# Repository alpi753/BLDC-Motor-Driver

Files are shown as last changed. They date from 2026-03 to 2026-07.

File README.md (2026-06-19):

# BLDC Motor Driver

Open-source BLDC ESC firmware for STM32 targets plus a desktop telemetry console. The repo contains KiCad hardware designs, two firmware builds (STM32F411 and STM32G431), and an Electron dashboard that decodes live motor data over USB.

Part of the broader [BLDC-Motor-Driver](https://github.com/alpi753/BLDC-Motor-Driver) project.

## Repository layout

```
PCB/
├── hardware/              KiCad schematics and PCBs (ESC, MCU, MOSFET boards)
├── software/
│   ├── console/           Electron + React telemetry dashboard
│   ├── stm32f411/         STM32F411CE firmware (CubeMX + CMake)
│   ├── stm32g431/         STM32G431CB firmware (CubeMX + CMake)
│   ├── shared/bsp/        Shared motor control, telemetry, USB/CBOR, DroneCAN
│   └── scripts/           Host-side utilities (e.g. telem_reader.py)
└── AGENTS.md              Contributor and AI-agent guide (architecture, protocol, gaps)
```

## Quick start

### Console (dashboard)

```bash
cd software/console
npm install
npm run dev
```

Linux USB serial access usually requires membership in the `dialout` group:

```bash
sudo usermod -a -G dialout $USER   # re-login required
```

### Firmware

Prerequisites: `arm-none-eabi-gcc`, `cmake`, `ninja` (and `openocd` for flashing).

**STM32F411**

```bash
cd software/stm32f411
cmake --preset Debug
cmake --build --preset Debug
make flash    # optional — ST-Link + OpenOCD
```

**STM32G431**

```bash
cd software/stm32g431
cmake --preset Debug
cmake --build --preset Debug
make flash
```

Select the board at configure time with `-DBLDC_BOARD=stm32f411` or `-DBLDC_BOARD=stm32g431` (default is `stm32g431` in the shared BSP CMake).

DroneCAN DSDL codegen (first build only, if `dsdl_generated/` is missing):

```bash
cd software/stm32f411   # or stm32g431
make dsdl_gen_build
```

## How it fits together

```
┌─────────────────────┐     USB CDC 115200 baud      ┌──────────────────────┐
│  STM32F411 / G431   │  CBOR [type, payload]        │  Electron main       │
│  TelemThread (~1Hz) │ ───────────────────────────► │  serial.ts decoder   │
│                     │ ◄─────────────────────────── │  ipc → React cards   │
└─────────────────────┘   settings CBOR (RX only)   └──────────────────────┘
         │
         ├── TIM1 complementary PWM → DRV8323 → 3-phase bridge
         ├── SPI1 → DRV8323R (enable, faults, gain, OC)
         └── ADC → phase currents, bus voltage, NTC temperature
```

Connect the board over USB, open the console, pick the CDC serial port, and dashboard cards update from live telemetry.

## Telemetry today

Both boards publish the same CBOR telemetry map when `CONFIG_BLDC_TELEM_USE_DEMO=n` (current default on both).

| Data | F411 | G431 |
|---|---|---|
| Phase currents (`i_a`–`i_c`) | Real — ADC1 DMA, PA0–PA2 | Real — ADC1 injected, PA0–PA2 |
| Bus voltage (`v_bat`) | Real — PA5 (`ADC1_IN5`) | Real — PB2 (`ADC2_IN12`) |
| Phase voltages (`v_a`–`v_c`) | Real — PWM duty × Vbus | Real — PWM duty × Vbus |
| FET temperature (`temp`) | Real — PA6 NTC, IIR filtered | Real — PA6 NTC, IIR + CORDIC/FMAC |
| Energy used (`e_used`) | Real — integrated V×I | Real — integrated V×I |
| Battery current (`i_bat`) | Approx — mean \|phase currents\| | Same |
| RPM, FOC (`i_d`/`i_q`), angles, observer fields | Stubbed 0 | Stubbed 0 |
| Energy remaining (`e_rem`) | Always 0 | Always 0 |
| Motor NTC (PA7) | Sampled, not telemetered | Sampled, not telemetered |

Telemetry rate is about **1 Hz** (one CBOR frame per second from `TelemThread`).

## What's not done yet

- Sensorless FOC and speed/position observers (RPM, angles, `i_d`/`i_q` stay at zero)
- Console settings UI → firmware settings over CBOR
- DroneCAN on the wire (libcanard layer exists; CAN HAL TX/RX not hooked up)
- `energy_rem` from battery capacity

For UI development without hardware, set `CONFIG_BLDC_TELEM_USE_DEMO=y` in the target's `software/shared/bsp/boards/<board>/board.conf` and rebuild.

## Documentation

- **[AGENTS.md](AGENTS.md)** — Full architecture, protocol reference, board differences, coding rules, and common tasks for contributors and AI agents.
- **[software/console/README.md](software/console/README.md)** — Console-specific setup, IPC API, and UI structure.

## License

No root-level LICENSE file is present yet. Check individual components and submodules for their terms.

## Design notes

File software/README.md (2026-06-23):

# BLDC Motor Driver

Open-source BLDC ESC firmware for STM32 targets plus a desktop telemetry console. This  two contains firmware builds (for both STM32F411 and STM32G431), and an Electron dashboard that decodes live motor data over USB (CAN in the future).

## Quick start

### Console

Linux USB serial access usually requires membership in the `dialout` group:

```bash
sudo usermod -a -G dialout $USER   # re-login required
```
Then: 

```bash
cd software/console
npm install
npm run dev
```

### Firmware

```bash
cd software/<board>
cmake --preset Debug -DBLDC_BOARD=<board>
cmake --build --preset Debug
make flash    # optional — ST-Link + OpenOCD
```

## How it fits together

```
┌─────────────────────┐  Trapezoid Comm./┌─────────────────────┐                              ┌──────────────────────┐
│  BLDC Motor         │  FOC Commutation │  STM32F411 / G431   │  CBOR [type, payload](TX/RX) │  Electron nodejs     │
│                     │◄─────────────────│  Telem     (~1Hz)   │ ───────────────────────────► │  decoder             │
│                     │◄─────────────────│                     │ ◄─────────────────────────── │      ipc → UI        │
└─────────────────────┘◄─────────────────└─────────────────────┘                              └──────────────────────┘
                              P.W.M          │
                                             ├── TIM1 complementary PWM → DRV8323 → 3-phase bridge
                                             ├── SPI1 → DRV8323R (enable, faults, gain, OC)
                                             └── ADC → phase currents, bus voltage, NTC temperature
```
           
Connect the board over USB, open the console, pick the CDC serial port, and dashboard cards update from live telemetry.

Telemetry rate is about **1 Hz** (one CBOR frame per second from `TelemThread`).

## What's not done yet

- Sensorless FOC and speed/position observers (RPM, angles, `i_d`/`i_q` stay at zero)
- DroneCAN not fully implemented yet.

For UI development without hardware, set `CONFIG_BLDC_TELEM_USE_DEMO=y` in the target's `software/shared/bsp/boards/<board>/board.conf` and rebuild.

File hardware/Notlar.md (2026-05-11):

## Motor sürücü devresi hakkında genel notlar

  Mosfet sürücü entegresinin akım sınırı yeterli mi analiz et.

Vin kaynağı için voltaj regülatörü ayarlanacak. İstediğim 6-60V aralığı, şimdilik elimde olan lm294 6-26V regülatörü kullanacağım.

Gate drievr entegresinin besleme hattına paralel kolda bağlı olan seri kapasitör bypass işi görmektedir. Yüksek frekans darbeleri emer ve devredeki ani akım çekimlerinde voltajı sabit tutma işi görür.

--high side - low side sürme
--faz Akım, faz gerilim, zıt emk rpm, mosfet sıcaklığı, rejeneratif kazanç??, kart sıcaklık bilgilerini toplama;  trickle charge pump to support 100% duty cycle. Bunun için;
Mosfet sürücü seçme / Devre kurma

%100 duty cycle destekli bootstrap devresi nasıl kurulur.

DRV8302- 360TL

Mosfet Seçimi
IAUCN08S7L013ATMA1	En iyisi, 1mohm RDSon 300A 80V

$x=y$

### Çalışma Koşulları
$Vbat = 50,4V (12S pil)$

$Inormal = 30A$

$Watt = 1,5kW$

Sistem bu veriler gözönünde bulundurularak tasarlanmıştır.

Her zaman önce **pull** sonra **push**!

### Termal analiz 
https://jrainimo.com/build/2024/11/oss-thermal-simulation-of-pcbs/
Açık kaynaklı programları kullanarak sıcaklık analizi yapılabilir.

### Board Tasarımında Dikkat Edilecek Hususlar
(https://www.youtube.com/watch?v=XKBNmYKVMiE)

Ringing ölçümü için alan bıraktığından emin ol. Osiloskop bağlayıp sinyali gözlemlemen gerekebilir.

Gronud Bounce??

Cross Talk: Birbiri üstünde gerilim indükleyerek yollardaki sinyalde bozulmaya yol açılmasıdır. Anahtarlama yolları sinyal yollarına yakın olmamalıdır.

HV ve LV bölgeleri birbirinden ayır. GND hatlarını da gnd plane üstünde birleştir.

Gate drive yol uzunluğunu azalt, indüktans azalsın. 
Yol genişliğini arttır, empedans azalsın. En iyisi, düşük empedans.
Via kullanmaktan kaçın mosfet Gate pininde.
Simetrik (Dif.) GH ve GL yolları çiz. Sinyaller aynı anda mosfetlere varsın. 
Gate drive yolları altına gnd plane atın.
GH GL dirençlerini mosfetlere yakın yerleştir ki mosfet sürücüyü ısıtmasın.

Birden fazla katmanda GND plane kullan ve vialarla geçişler yap ki gnd empedansı azalsın.

Yol uzunlukları ve via sayısını minimize et.

CURRENT SENSE: 
  Şönt direnç yollarını ground kalkanlama ve via ile çerçeveleme ile EMI'dan koru.

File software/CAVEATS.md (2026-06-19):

# Software caveats

Known gaps, risks, and incomplete paths in `software/` as of the current tree. Use this before bench tuning, demos, or production assumptions.

For architecture and build instructions see [`../AGENTS.md`](../AGENTS.md).

---

## What is in good shape

| Area | Status |
|---|---|
| Phase currents, Vbus, FET temp, phase voltages (duty × Vbus), energy used | Real ADC on both boards when `CONFIG_BLDC_TELEM_USE_DEMO=n` |
| USB CDC telemetry | CBOR `[0, map]` at 115200 baud, ~1 kHz (`CONFIG_TELEM_TX_HZ=1000`) |
| Settings host → device | CBOR `[1, map]` decoded in `telem.c`; live PI apply via `bldc_foc_apply_settings()` |
| G431 sensorless FOC path | TIM1 OC4REF → ADC1 injected, 10 kHz loop, idle until `rpm_t > 0` |
| G431 DRV8323 SPI | 8-bit, soft NSS, ~1.3 Mbit/s (`stm32g431.ioc` + `main.c`) |
| Console dashboard | Live charts when connected; settings window sends CBOR |
| Shared BSP | Single public header: `shared/bsp/bsp.h` |

---

## Board defaults (`board.conf`)

| Flag | STM32F411 | STM32G431 |
|---|---|---|
| `CONFIG_FOC_ENABLE` | **n** | **y** |
| `CONFIG_BLDC_TELEM_USE_DEMO` | n | n |
| `CONFIG_TELEM_TX_HZ` | 1000 | 1000 |
| `CONFIG_FOC_LOOP_HZ` | 10000 | 10000 |
| `CONFIG_BLDC_HAS_HW_ACCEL` | no | yes (CORDIC, FMAC) |
| ADC | 6-ch DMA circular (ADC1) | Dual ADC: injected phase + polled slow |

Build either target:

```bash
cd software/stm32f411   # or stm32g431
cmake --preset Debug && cmake --build --preset Debug
```

---

## Critical — verify before spin

### F411: FOC is off and not PWM-synced

With `CONFIG_FOC_ENABLE=y` on F411, `bsp_foc_sample_sensors()` reads the **telem DMA snapshot**, not PWM-aligned samples. G431 uses hardware injection on TIM1 TRGO. Do not expect F411 FOC parity without new ADC timing work.

**Path:** `boards/stm32f411/board.c`, `boards/stm32f411/board.conf`

### DroneCAN: protocol only, no bus I/O

`dronecan.c` initializes libcanard and publishes from `TelemThread`, but:

- `bldc_dronecan_update()` has no FDCAN RX/TX (no `HAL_FDCAN_Start`, no IRQ bridge).
- `handle_RawCommand()` ignores motor commands.
- ESC status uses placeholder values (12 V, 0 A, 0 RPM).
- Param get/set and execute-opcode handlers are empty.
- Node ID is hardcoded to **42**; DNA handlers exist but `should_accept_transfer()` does not accept DNA broadcasts.
- F411: `bldc_dronecan_init()` is **commented out** in `main.c`.

**Path:** `shared/bsp/dronecan.c`, `stm32g431/Core/Src/main.c`, `stm32f411/Core/Src/main.c`

### CubeMX regeneration risks (G431)

| Item | Risk |
|---|---|
| **TIM1 CH4** | Internal OC4REF for ADC trigger is in `/* USER CODE BEGIN TIM1_Init 2 */` in `main.c`. CubeMX often omits CH4 when it has no pin — regen can break FOC ADC while leaving `TIM_TRGO_OC4REF`. |
| **SPI1 DataSize** | Must stay `SPI_DATASIZE_8BIT` in `.ioc` / `main.c` for DRV8323 16-bit frames over two bytes. |
| **ADC1_2_IRQHandler** | Must live only in `stm32g4xx_it.c`, not `boards/stm32g431/board.c` (duplicate symbol). |
| HAL outside USER CODE | Edits to generated `MX_*_Init()` / `*_hal_msp.c` are overwritten — change `.ioc` instead. |

### Motor spins only when commanded

`rpm_target` defaults to **0** (idle). Setting `rpm_t > 0` in settings and sending over USB starts the startup sequence. There is no separate “arm” flag beyond that.

---

## FOC and motor control

### Observer model

- Simplified sliding-mode current observer + PLL in `observer.c` — not a full Luenberger/PLL reference design.
- `Id` target is hardcoded **0** (no field weakening).
- Motor model params `rs`, `ls`, `obs` must be reasonable; wrong values cause hand-off failure or instability.
- No ADC **zero-offset calibration** at boot; standstill current assumes `PHASE_CURRENT_ZERO_V = 1.65 V`.

### Current / voltage limits

- Current PI output clamps use **`FOC_DEFAULT_VBUS` (24 V)**, not measured `v_bat`, at init (`foc_pi_init`). High pack voltage can saturate the current loop early.
- Only **`l_i` (`max_phase_current`)** is enforced in closed-loop on `Iq`. Alignment and open-loop currents are capped by `l_i` only where `foc_open_loop_current()` applies; no thermal or bus-voltage shutdown.

### G431 Vbus in the FOC loop

Phase currents are PWM-synchronous; **Vbus is cached ~1 Hz** from ADC2 slow scan during FOC (`g431_foc_refresh_vbus_cache`). Decoupling and duty scaling can lag real bus transients.

**Path:** `boards/stm32g431/board.c`

### PWM frequency

TIM1 defaults (CubeMX): `Period = 65535`, `Prescaler = 0` → PWM frequency in the **low kHz** range (clock-dependent). Audible noise and current ripple may be high vs a typical 20–40 kHz ESC target.

### Startup and hand-off (recent behavior)

All modes eventually require **observer readiness** before closed-loop speed control:

| Criterion | Setting (CBOR key) | Default |
|---|---|---|
| Open-loop RPM ≥ min CL | `min_cl` | 500 |
| PLL locked | telemetry `pll` | — |
| Observer confidence ≥ threshold | `ho_conf` | 55 |
| Angle error ≤ threshold | `ho_ae` | 25° |

| `smode` | Behavior |
|---|---|
| 0 | Align → open-loop from `ol_start` → hand-off → closed-loop |
| 1 | Skip align; open-loop from `ol_start` |
| 2 | Skip align; open-loop starts at **`min_cl` RPM** (not instant closed-loop) |

- `ramp` (ms) limits **acceleration time** only; after timeout, RPM holds until hand-off criteria are met (no blind hand-off on timeout).
- `ol_i` — open-loop torque current (separate from `align`).
- `ol_start` — entry RPM after align / mode 1 (capped by `min_cl`, `max_ol`).

Changing `pp` / `rs` / `ls` over USB updates observer gains but **does not reset** observer state; stop (`rpm_t = 0`) and restart after large motor-param changes.

### Fault handling

`foc_gate_driver_ok()` reads DRV8323 faults and calls `bldc_drv8323r_reset_faults()` — faults are cleared automatically, not surfaced on USB. Persistent hardware faults may be masked.

### Tasking

| Task | Priority | Stack (G431) | Role |
|---|---|---|---|
| `commTask` | Above normal | 512×4 | FOC loop when enabled |
| `telemTask` | Low | 512×4 | USB TX + DroneCAN pub |
| `defaultTask` | Normal | 128×4 | USB init + idle loop |

FOC at 10 kHz with trig/`sqrtf` on a 2 KB stack — watch for overflow under load.

### F411 without FOC

`CommThread` runs **trapezoidal** 6-step commutation at fixed duty (`BLDC_COMM_DUTY_PERCENT`). RPM comes from settings `max_ol` if set, else defaults in `commutation.c`.

---

## Telemetry and sensing

| Field | Notes |
|---|---|
| `i_a`–`i_c` | Shunt scaling `PHASE_CURRENT_V_PER_A = 0.1 V/A`, zero 1.65 V |
| `v_bat` | Divider × 11; F411 PA5, G431 PB2 (slow ADC) |
| `v_a`–`v_c` | `duty × v_bat`; no dead-time / neutral shift (see `telem.c` TODO) |
| `i_bat` | **Approximation**: mean \|phase current\|, not bus shunt |
| `e_used` | Integrated from approx `i_bat` × `v_bat` |
| `e_rem` | Always **0**; `BATTERY_CAPACITY_WH` unused |
| `temp` | FET NTC (PA6) only; motor NTC (PA7) sampled but **not telemetered** |
| `rpm`, `i_d`/`i_q`, angles, observer | Populated when `CONFIG_FOC_ENABLE`; else zero / stubs |
| `id` | 16-byte UID in CBOR key `"id"` |

Telem snapshot on G431 during FOC reads the **FOC ADC cache** when HW trigger is active; otherwise polled injected ranks.

**Path:** `shared/bsp/telem.c`, board `board.c` files

---

## USB and settings protocol

- **Encode:** `usb_telem_encode` / `settings_encode` in `telem.c`.
- **RX:** `usb_msg_rx` in `telem.c` → `bldc_foc_apply_settings()` when FOC enabled.
- **TX blocking:** `usb_send_blocking()` retries with `osDelay` — backpressure can add jitter to `telemTask`.
- **Double USB init:** `bsp_usb_init()` in `bldc_telem_init()` (pre-scheduler) and `MX_USB_Device_Init()` again in `defaultTask` / `MainTask`.
- **Settings not stored in flash** — reboot restores firmware defaults until host re-sends.
- **No settings readback** from MCU to host (one-way apply).

### Active settings keys (23)

`pp`, `rs`, `ls`, `i_kp`, `i_ki`, `s_kp`, `s_ki`, `p_kp`, `p_ki`, `obs`, `min_cl`, `max_ol`, `ramp`, `align_t`, `ol_ramp`, `align`, `ol_i`, `ol_start`, `ho_ae`, `ho_conf`, `rpm_t`, `smode`, `l_i`

Removed from protocol (unused or misleading): `kv`, `idt`, `bemf` filter, `l_v`, `l_t`, `l_cd`.

Console local storage key: `bldc.motor-settings.v4` (`console/src/lib/motor-settings.ts`).

---

## Console (`software/console/`)

### Demo fallbacks mask disconnect

All dashboard cards (`src/cards/*.tsx`) show **synthetic demo data** when history is empty. Charts can look “live” with no device connected — verify `device_id` / connection state before tuning.

### Telemetry validation is partial

`electron/lib/serial.ts` `isTelemetryPayload()` checks only rpm, currents, voltages, and timestamp — not `id`, observer fields, or `i_d`/`i_q`.

### No in-dashboard RPM setpoint

Target RPM is **`rpm_t` in Settings** → Save & Send. No throttle slider on the main dashboard.

### Lint / CI

`npm run lint` fails on pre-existing issues (generated `dist-electron/`, shadcn refresh rules, etc.) — not a clean gate today.

### IPC gaps

- `file:save-file` exists in main process; no dashboard wiring for session capture.
- Settings RX from device (`onSettings`) is typed but not used for MCU → host sync.

---

## Build and tooling

| Topic | Caveat |
|---|---|
| **clangd** | Root `.clangd` defaults to F411 build; G431 FOC work may need `compile_commands.json` from `stm32g431/build/Debug`. |
| **DroneCAN DSDL** | Generated sources under `Middlewares/Third_Party/dsdl_generated/`; run `make dsdl_gen_build` if missing. |
| **libcanard** | Submodule under each target; `canard_stm32` driver exists but is **not linked** into the app HAL path. |
| **`#include "dronecan.c"`** | DroneCAN compiled into `telem.c` translation unit — unusual for tests and linking boundaries. |
| **F411 DRV8323** | `bldc_drv8323r_init()` commented in `main.c`; commutation/FOC paths call it from threads when used. |

---

## Scripts

`software/scripts/telem_reader.py` — standalone CBOR telemetry decoder for bring-up without the Electron app. Settings TX and FOC control not covered.

---

## Suggested bring-up order

1. Flash G431 (or F411 trapezoidal only with `CONFIG_FOC_ENABLE=n`).
2. Connect console; confirm **real** `i_a`–`i_c`, `v_bat`, `temp` (ignore demo card data until history populates).
3. Send settings with **`rpm_t = 0`**; confirm motor stays idle.
4. Set conservative startup: `smode=0`, low `align` / `ol_i`, `ol_start=150`, `min_cl=500`, `ho_ae=30`, `ho_conf=50`.
5. Set `rpm_t` > 0 and send; watch `pll`, `obs`, `ang_err` until hand-off.
6. Tune `obs`, PLL, then current/speed loops.
7. Do not rely on DroneCAN, `e_rem`, or `i_bat` for safety decisions until implemented.

---

## High-leverage fixes (not done)

1. FDCAN RX/TX bridge + wire `RawCommand` → `rpm_t` / torque.
2. Remove or gate dashboard demo fallbacks when disconnected.
3. Live Vbus in current PI limits and faster G431 Vbus in FOC.
4. Thermal / bus over-voltage protection (real limits, not removed settings).
5. F411 PWM-sync ADC if FOC on F411 is required.
6. Persist settings to flash or echo settings map on request.
7. ADC zero calibration at boot.

---

*Update this file when closing a gap or changing defaults in `board.conf`, CBOR keys, or startup logic.*

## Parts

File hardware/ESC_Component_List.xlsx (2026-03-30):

Digi-Key: Shopping Cart
Index | Quantity | Part Number | Manufacturer Part Number | Description | Customer Reference | Available | Backorder | Unit Price | Extended Price USD
1 | 1 | 296-47769-1-ND | DRV8323RSRGZR | IC MTR DRV MULTIPHAS 6-60V 48QFN |  | 1 | 0 | 4.53 | 4.53
2 | 1 | 497-19475-ND | STM32G431CBU6 | IC MCU 32BIT 128KB FLSH 48UFQFPN |  | 1 | 0 | 5.06 | 5.06
3 | 10 | 1276-1513-1-ND | CL05B105KQ5NQNC | CAP CER 1UF 6.3V X7R 0402 |  | 10 | 0 | 0.077 | 0.77
4 | 10 | 1276-6807-1-ND | CL10B104KC8NNNC | CAP CER 0.1UF 100V X7R 0603 |  | 10 | 0 | 0.048 | 0.48
5 | 25 | 399-C0603C105K4RACTUCT-ND | C0603C105K4RACTU | CAP CER 1UF 16V X7R 0603 |  | 25 | 0 | 0.011 | 0.28
6 | 10 | 1276-6526-1-ND | CL21A226KOQNNNE | CAP CER 22UF 16V X5R 0805 |  | 10 | 0 | 0.209 | 2.09
7 | 2 | SS18CT-ND | SS18 | DIODE SCHOTTKY 80V 1A DO214AC |  | 2 | 0 | 0.18 | 0.36
8 | 10 | RMCF0603ZT0R00CT-ND | RMCF0603ZT0R00 | RES 0 OHM JUMPER 1/10W 0603 |  | 10 | 0 | 0.006 | 0.06
9 | 10 | 311-2.2HRCT-ND | RC0603FR-072R2L | RES 2.2 OHM 1% 1/10W 0603 |  | 10 | 0 | 0.011 | 0.11
10 | 10 | 311-4.7GRCT-ND | RC0603JR-074R7L | RES 4.7 OHM 5% 1/10W 0603 |  | 10 | 0 | 0.01 | 0.10
11 | 2 | 587-2952-1-ND | NRS6045T220MMGK | FIXED IND 22UH 1.6A 139.1MOHM SM |  | 2 | 0 | 0.26 | 0.52
12 | 10 | 478-08056D104KAT2ACT-ND | 08056D104KAT2A | CAP CER 0.1UF 6.3V X5R 0805 |  | 10 | 0 | 0.045 | 0.45
13 | 25 | 311-10.0KHRCT-ND | RC0603FR-0710KL | RES 10K OHM 1% 1/10W 0603 |  | 25 | 0 | 0.0056 | 0.14
14 | 25 | 311-100KHRCT-ND | RC0603FR-07100KL | RES 100K OHM 1% 1/10W 0603 |  | 25 | 0 | 0.0056 | 0.14
15 | 25 | RNCP0603FTD1K00CT-ND | RNCP0603FTD1K00 | RES 1K OHM 1% 1/8W 0603 |  | 25 | 0 | 0.0108 | 0.27
16 | 25 | 311-3.30KHRCT-ND | RC0603FR-073K3L | RES 3.3K OHM 1% 1/10W 0603 |  | 25 | 0 | 0.0088 | 0.22
17 | 3 | 1189-1701-1-ND | 80ZLJ680MGC18X25 | CAP ALUM 680UF 20% 80V RADIAL TH |  | 3 | 0 | 2.93 | 8.79
18 | 25 | 311-4.70KHRCT-ND | RC0603FR-074K7L | RES 4.7K OHM 1% 1/10W 0603 |  | 25 | 0 | 0.0056 | 0.14
19 | 25 | RMCF0603FT91K0CT-ND | RMCF0603FT91K0 | RES 91K OHM 1% 1/10W 0603 |  | 25 | 0 | 0.0056 | 0.14
20 | 10 | 1276-CL10B103KO8WPNCCT-ND | CL10B103KO8WPNC | CAP CER 10NF 16V X7R 0603 |  | 10 | 0 | 0.043 | 0.43
21 | 2 | 31-AP64500SP-13CT-ND | AP64500SP-13 | IC REG BUCK ADJ 5A 8SO |  | 2 | 0 | 2.09 | 4.18
22 | 10 | P47KGCT-ND | ERJ-3GEYJ473V | RES SMD 47K OHM 5% 1/10W 0603 |  | 10 | 0 | 0.032 | 0.32
23 | 10 | 490-GRM21BD72A225KE01LCT-ND | GRM21BD72A225KE01L | CAP CER 2.2UF 100V X7T 0805 |  | 10 | 0 | 0.255 | 2.55
24 | 2 | 553-BWVS00505040220M00CT-ND | BWVS00505040220M00 | FIXED IND 22UH 1.4A 135 MOHM SMD |  | 2 | 0 | 0.33 | 0.66
25 | 2 | XC2076CT-ND | ECS-80-20-5PX-TR | CRYSTAL 8.0000MHZ 20PF SMD |  | 2 | 0 | 0.28 | 0.56
26 | 1 | BZT52C3V3-E3-08GICT-ND | BZT52C3V3-E3-08 | DIODE ZENER 3.3V 410MW SOD123 |  | 1 | 0 | 0.15 | 0.15
27 | 2 | 296-44212-1-ND | TCAN337DR | IC TRANSCEIVER 1/1 8SOIC |  | 2 | 0 | 2.24 | 4.48
28 | 5 | P12011CT-ND | ERT-J1VG103FA | THERMISTOR NTC 10KOHM 3380K 0603 |  | 5 | 0 | 0.156 | 0.78
29 | 10 | CRF2512-FZ-R002ELFCT-ND | CRF2512-FZ-R002ELF | RES 0.002 OHM 1% 2W 2512 |  | 10 | 0 | 0.312 | 3.12
30 | 10 | 311-5.6KDCT-ND | RT0603DRD075K6L | RES SMD 5.6K OHM 0.5% 1/10W 0603 |  | 10 | 0 | 0.03 | 0.30
31 | 10 | MMSZ3V3T1GOSCT-ND | MMSZ3V3T1G | DIODE ZENER 3.3V 500MW SOD123 |  | 10 | 0 | 0.056 | 0.56
32 | 10 | 2223-TS04-66-73-BK-260-SMT-ND | TS04-66-73-BK-260-SMT | SWITCH TACTILE SPST-NO 0.05A 12V |  | 10 | 0 | 0.16 | 1.60
33 | 10 | 732-7817-1-ND | 885012007013 | CAP CER 33PF 16V C0G/NP0 0805 |  | 10 | 0 | 0.053 | 0.53
34 | 20 | 1uF 6.3V 10% x5R 603 SMD Kondansatör |  | https://www.direnc.net/1uf-16v-10-x5r-603-smd-kondansator |  |  |  | 0.1818181818
35 | 20 | 1uF 16V 10% x5R 603 SMD Kondansatör (https://www.direnc.net/1uf-50v-10-603-smd-kondansator) |  |  |  |  |  | 0.1590909091
36 | 20 | 100nF 50V 10% x7R 805 SMD Kondansatör (https://www.direnc.net/100nf50v-805-kilif) |  |  |  |  |  | 0.1363636364

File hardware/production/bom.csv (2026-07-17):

Designator | Footprint | Quantity | Value | LCSC Part #
BATT+1, BATT-1 | Power_pad_smd | 2 | power_pad_smd
C10 | 0603 | 1 | 22uF 16V
C11 | 0805 | 1 | 0.1uF 6.3V
C12 | CAPC1608X90N | 1 | 1uF 16V
C13 | CAPC1608X90N | 1 | 0.1 uF 100V
C14 | CAPPRD250W50D655H1250 | 1 | 22uF 100V
C15, C16, C17 | 0603 | 3 | 10nF
C18, C32 | 0603 | 2 | 1uF
C19, C20, C28 | 0603 | 3 | 1uF | C52923
C21 | 0603 | 1 | 4u7 | C19666
C22, C23, C24, C26, C31 | 0603 | 5 | 100nF | C1525
C25, C27 | 0603 | 2 | 33pF
C29 | 0603 | 1 | 10nF | C15195
C30 | 0603 | 1 | 100nF
C33, C34, C35, C36, C38 | 0603 | 5 | 2.2uF
C37, C39 | CAPPRD750W85D1600H2700 | 2 | 680uF 80V
C6, C9 | 0603 | 2 | 47nF 100V
C7 | 0603 | 1 | 0.1uF 16V
C8 | 0603 | 1 | 1uF 6.3V
D1 | DIOM5227X270N | 1 | SS18 80V 1A
D2 | 0603 | 1 | LEDA
D3 | 0603 | 1 | LEDB
D4 | 0603 | 1 | LEDC
D5 | SOT95P280X145-6N | 1 | USBLC6-2SC6Y
D6 | SOD3716X135N | 1 | D_Zener
D7 | DIOM5127X229N | 1 | SMAJ5.0A-E3_61
IC1 | SOT65P280X145-8N | 1 | TCAN330DCNT
J1, J5 | JST_BM04B-GHS-TBT_LF__SN__N_ | 2 | BM04B-GHS-TBT_LF__SN__N_
J2 | USB_C_Receptacle_GCT_USB4105-xx-A_16P_TopMnt_Horizontal | 1 | USB_C_Receptacle_USB2.0_16P
J3 | TerminalBlock_MaiXu_MX126-5.0-02P_1x02_P5.00mm | 1 | Conn_01x02_Socket
J4 | PinHeader_1x04_P2.54mm_Vertical | 1 | Conn_01x04_Pin
L1 | INDM7676X355N | 1 | 22uH 1.6A | DR73-220-R
L2 | 0603 | 1 | 100MHz / 1kR | C26443
Q10, Q11, Q12, Q7, Q8, Q9 | STL90N6F7_Thermal_Vias | 6 | STL90N6F7
R1, R2 | 0603 | 2 | 5.1k | C25744
R10, R12, R14 | 0603 | 3 | 91k
R11, R13, R15 | 0603 | 3 | 4k7
R16, R17, R26, R5, R9 | 0603 | 5 | 10k
R18, R19, R20 | 0603 | 3 | 330R
R21, RGA3, RGA4, RGB3, RGB4, RGC3, RGC4 | RESC1508X55N | 7 | 0ohm
R22 | 0603 | 1 | 10k | C25744
R23 | 0603 | 1 | 3.3k
R24, R4 | 0603 | 2 | 100k
R25, R28, R7 | 0603 | 3 | 1k
R27 | 0603 | 1 | 120R
R6 | RESC1607X60N | 1 | 5k6
RSENSE_A4, RSENSE_A5, RSENSE_B4, RSENSE_B5, RSENSE_C4, RSENSE_C5 | RESC6432X80N | 6 | 2mohm
SW2, W1 | SW_SPDT_PCM12 | 2 | SW_SPDT
TH1 | 0603 | 1 | ERT-J1VG103FA
U1 | QFN50P700X700X100-49N | 1 | DRV8323RSRGZR
U2 | SOT-23-5 | 1 | ME6211C33M5
U3 | QFN50P700X700X60-49N | 1 | STM32G431CBU6
Y1 | XTAL_ECS-80-20-5PX-TR | 1 | ECS-80-20-5PX-TR
Z1, Z2 | KDZLVTR56 | 2 | KDZLVTR56

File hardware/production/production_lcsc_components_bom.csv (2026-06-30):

Designator | Footprint | Quantity | Value | LCSC Part #
BATT+1, BATT-1 | Power_pad_smd | 2 | power_pad_smd
C10 | 603 | 1 | 22uF 16V | C2762594
C11 | CAPC2012X140N | 1 | 0.1uF 6.3V | C5445386
C12 | CAPC1608X90N | 1 | 1uF 16V | C696901
C13 | CAPC1608X90N | 1 | 0.1 uF 100V | C20069879
C14 | CAPPRD250W50D655H1250 | 1 | 22uF 100V | C437651
C15, C16, C17 | 603 | 3 | 10nF | C163179
C18, C32 | 603 | 2 | 1uF | C696901
C19, C20, C28 | 603 | 3 | 1uF | C696901
C21 | 603 | 1 | 4u7 | C8032
C22, C23, C24, C26, C31 | 603 | 5 | 100nF | C53084461
C25, C27 | 603 | 2 | 33pF | C18220913
C29 | 603 | 1 | 10nF | C15195
C30 | 603 | 1 | 100nF | C53084461
C33, C34, C35, C36, C38 | 603 | 5 | 2.2uF | C20539433
C37, C39 | CAPPRD750W85D1600H2700 | 2 | 680uF 80V | C407989
C6, C9 | 603 | 2 | 47nF 100V | C599763
C7 | 603 | 1 | 0.1uF 16V | C20539422
C8 | 603 | 1 | 1uF 6.3V | C105524
D1 | DIOM5227X270N | 1 | SS18 80V 1A | C2898405
D2 | 603 | 1 | LEDA | C51933292
D3 | 603 | 1 | LEDB | C7496818
D4 | 603 | 1 | LEDC | C51933294
D5 | SOT95P280X145-6N | 1 | USBLC6-2SC6Y | C2969755
D6 | SOD3716X135N | 1 | D_Zener | C7529058
D7 | DIOM5127X229N | 1 | SMAJ5.0A-E3_61 | C89363
IC1 | SOT65P280X145-8N | 1 | TCAN330DCNT | C2671056
J1, J5 | JST_BM04B-GHS-TBT_LF__SN__N_ | 2 | BM04B-GHS-TBT_LF__SN__N_
J2 | USB_C_Receptacle_GCT_USB4105-xx-A_16P_TopMnt_Horizontal | 1 | USB_C_Receptacle_USB2.0_16P | C3025063
J3 | TerminalBlock_MaiXu_MX126-5.0-02P_1x02_P5.00mm | 1 | Conn_01x02_Socket
J4 | PinHeader_1x04_P1.00mm_Vertical | 1 | Conn_01x04_Pin
L1 | INDM7676X355N | 1 | 22uH 1.6A | C167971
L2 | 603 | 1 | 100MHz / 1kR | C76814
Q10, Q11, Q12, Q7, Q8, Q9 | STL90N6F7_Thermal_Vias | 6 | STL90N6F7 | C221506
R10, R12, R14 | 603 | 3 | 91k | C2907077
R11, R13, R15 | 603 | 3 | 4k7 | C3016318
R16, R17, R26, R5, R8, R9 | 603 | 6 | 10k | C95204
R18, R19, R20 | 603 | 3 | 330R | C2907152
R21, RGA3, RGA4, RGB3, RGB4, RGC3, RGC4 | RESC1508X55N | 7 | 0ohm | C1512169
R22 | 603 | 1 | 10k | C95204
R23 | 603 | 1 | 3.3k | C2907140
R24, R4 | 603 | 2 | 100k | C2907088
R25, R28, R7 | 603 | 3 | 1k | C3016283
R27 | 603 | 1 | 120R | C114640
R6 | RESC1607X60N | 1 | 5k6 | C2907046
RSENSE_A4, RSENSE_A5, RSENSE_B4, RSENSE_B5, RSENSE_C4, RSENSE_C5 | RESC6432X80N | 6 | 2mohm | C4198046
SW1, SW2 | SW_SPDT_PCM12 | 2 | SW_SPDT | C221841
TH1 | 603 | 1 | ERT-J1VG103FA | C153011
U1 | QFN50P700X700X100-49N | 1 | DRV8323RSRGZR | C2653553
U2 | SOT-23-5 | 1 | ME6211C33M5 | C82942
U3 | QFN50P700X700X60-49N | 1 | STM32G431CBU6 | C529356
Y1 | XTAL_ECS-80-20-5PX-TR | 1 | ECS-80-20-5PX-TR | C2441302
Z1, Z2 | KDZLVTR56 | 2 | KDZLVTR56 | C3737443

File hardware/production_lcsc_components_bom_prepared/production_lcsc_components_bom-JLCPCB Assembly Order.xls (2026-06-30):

JLCPCB BOM Tool - BOM Matching
BOM name：production_lcsc_components_bom-JLCPCB Assembly Order.xlsx |  |  | Download Time：2026-05-18 21:01:26 |  |  |  | * Our matching results are updated in real-time, but stock and prices may change. If it's been over 24 hours, please re-match before placing your order.
PCB Assembled Qty：5 |  |  | Est. Total Price：66.0730
Your BOM |  |  |  |  | Matched Parts |  |  |  |  |  |  | Order Information
Top Designator | Bottom Designator | Comment | Footprint | JLCPCB Part # | Matches | Part # | Manufacturer | Footprint | Description | Category | Warning | JLCPCB Part # | Product link | Lib Type | Qty | Source | Total Price ($)
C6,C9 |  | 47nF100V | 603 |  | Select by System | C0603C473K1RECAUTO | KEMET | 0603 | 100V 47nF X7R ±10% 0603 Multilayer Ceramic Capacitors MLCC - SMD/SMT ROHS | Multilayer Ceramic Capacitors MLCC - SMD/SMT |  | C599763 | https://jlcpcb.com/partdetail/KEMET-C0603C473K1RECAUTO/C599763 | Extended | 5 | 5 JLCPCB | 0.1955
C7 |  | 0.1uF16V | 603 |  | Select by Customer | CC0603KRX7R9BB104 | YAGEO | 0603 | 100nF 50V X7R ±10% 0603 Multilayer Ceramic Capacitors MLCC - SMD/SMT ROHS | Multilayer Ceramic Capacitors MLCC - SMD/SMT | 1.Multiple lines in the BOM have been matched to the same part. Please check if the matching is correct. ; | C14663 | https://jlcpcb.com/partdetail/YAGEO-CC0603KRX7R9BB104/C14663 | Basic | 14 | 14 JLCPCB | 0.042
C22,C23,C24,C26,C31 |  | 100nF | 603 |  | Select by Customer | CC0603KRX7R9BB104 | YAGEO | 0603 | 100nF 50V X7R ±10% 0603 Multilayer Ceramic Capacitors MLCC - SMD/SMT ROHS | Multilayer Ceramic Capacitors MLCC - SMD/SMT | 1.Multiple lines in the BOM have been matched to the same part. Please check if the matching is correct. ; | C14663 | https://jlcpcb.com/partdetail/YAGEO-CC0603KRX7R9BB104/C14663 | Basic | 14 | 14 JLCPCB | 0.042
C30 |  | 100nF | 603 |  | Select by Customer | CC0603KRX7R9BB104 | YAGEO | 0603 | 100nF 50V X7R ±10% 0603 Multilayer Ceramic Capacitors MLCC - SMD/SMT ROHS | Multilayer Ceramic Capacitors MLCC - SMD/SMT | 1.Multiple lines in the BOM have been matched to the same part. Please check if the matching is correct. ; | C14663 | https://jlcpcb.com/partdetail/YAGEO-CC0603KRX7R9BB104/C14663 | Basic | 14 | 14 JLCPCB | 0.042
C8 |  | 1uF6.3V | 603 |  | Select by System | CL10B105KQ8NNNC | Samsung Electro-Mechanics | 0603 | 1uF 6.3V X7R ±10% 0603 Multilayer Ceramic Capacitors MLCC - SMD/SMT ROHS | Multilayer Ceramic Capacitors MLCC - SMD/SMT |  | C105524 | https://jlcpcb.com/partdetail/106739-CL10B105KQ8NNNC/C105524 | Extended | 20 | 20 JLCPCB | 0.122
C10 |  | 22uF16V | 603 |  | Select by System | CL10A226MO7JZNC | Samsung Electro-Mechanics | 0603 | 16V 22uF X5R ±20% 0603 Multilayer Ceramic Capacitors MLCC - SMD/SMT ROHS | Multilayer Ceramic Capacitors MLCC - SMD/SMT |  | C2762594 | https://jlcpcb.com/partdetail/2889856-CL10A226MO7JZNC/C2762594 | Extended | 6 | 6 JLCPCB | 0.2976
C12 |  | 1uF16V | CAPC1608X90N |  | Select by Customer | CL10A105KB8NNNC | Samsung Electro-Mechanics | 0603 | 1uF 50V X5R ±10% 0603 Multilayer Ceramic Capacitors MLCC - SMD/SMT ROHS | Multilayer Ceramic Capacitors MLCC - SMD/SMT | 1.Multiple lines in the BOM have been matched to the same part. Please check if the matching is correct. ; | C15849 | https://jlcpcb.com/partdetail/16531-CL10A105KB8NNNC/C15849 | Basic | 12 | 12 JLCPCB | 0.0912
C18,C32 |  | 1uF | 603 |  | Select by Customer | CL10A105KB8NNNC | Samsung Electro-Mechanics | 0603 | 1uF 50V X5R ±10% 0603 Multilayer Ceramic Capacitors MLCC - SMD/SMT ROHS | Multilayer Ceramic Capacitors MLCC - SMD/SMT | 1.Multiple lines in the BOM have been matched to the same part. Please check if the matching is correct. ; | C15849 | https://jlcpcb.com/partdetail/16531-CL10A105KB8NNNC/C15849 | Basic | 12 | 12 JLCPCB | 0.0912
C19,C20,C28 |  | 1uF | 603 |  | Select by Customer | CL10A105KB8NNNC | Samsung Electro-Mechanics | 0603 | 1uF 50V X5R ±10% 0603 Multilayer Ceramic Capacitors MLCC - SMD/SMT ROHS | Multilayer Ceramic Capacitors MLCC - SMD/SMT | 1.Multiple lines in the BOM have been matched to the same part. Please check if the matching is correct. ; | C15849 | https://jlcpcb.com/partdetail/16531-CL10A105KB8NNNC/C15849 | Basic | 12 | 12 JLCPCB | 0.0912
C13 |  | 0.1uF100V | CAPC1608X90N |  | Select by System | CSA0603X7R104K101JT | HRE | 0603 | 0603 Multilayer Ceramic Capacitors MLCC - SMD/SMT ROHS |  |  | C20069879 | https://jlcpcb.com/partdetail/HRE-CSA0603X7R104K101JT/C20069879 | Extended | 20 | 20 JLCPCB | 0.068
C14 |  | 22uF100V | CAPPRD250W50D655H1250 |  | Select by System | 100YXJ22M6.3X11 | Rubycon | 插件,D6.3xL11mm | -40℃~+105℃ 100V 11mm 2.5mm 22uF 267mA@100kHz 6.3mm 7000hrs@105℃ ±20% 插件,D6.3xL11mm Aluminum Electrolytic Capacitors - Leaded ROHS | Aluminum Electrolytic Capacitors - Leaded |  | C437651 | https://jlcpcb.com/partdetail/Rubycon-100YXJ22M63X11/C437651 | Extended | 3 | 3 JLCPCB | 0.2559
C15,C16,C17 |  | 10nF | 603 |  | Select by Customer | 0603B103K500NT | FH (Guangdong Fenghua Advanced Tech) | 0603 | 10nF 50V X7R ±10% 0603 Multilayer Ceramic Capacitors MLCC - SMD/SMT ROHS | Multilayer Ceramic Capacitors MLCC - SMD/SMT |  | C57112 | https://jlcpcb.com/partdetail/58143-0603B103K500NT/C57112 | Basic | 6 | 6 JLCPCB | 0.0186
C21 |  | 4u7 | 603 |  | Select by Customer | CL10A475KO8NNNC | Samsung Electro-Mechanics | 0603 | 16V 4.7uF X5R ±10% 0603 Multilayer Ceramic Capacitors MLCC - SMD/SMT ROHS | Multilayer Ceramic Capacitors MLCC - SMD/SMT |  | C19666 | https://jlcpcb.com/partdetail/20375-CL10A475KO8NNNC/C19666 | Basic | 2 | 2 JLCPCB | 0.022
C25,C27 |  | 33pF | 603 |  | Select by Customer | CL10C330JB8NNNC | Samsung Electro-Mechanics | 0603 | 33pF 50V C0G ±5% 0603 Multilayer Ceramic Capacitors MLCC - SMD/SMT ROHS | Multilayer Ceramic Capacitors MLCC - SMD/SMT |  | C1663 | https://jlcpcb.com/partdetail/2015-CL10C330JB8NNNC/C1663 | Basic | 4 | 4 JLCPCB | 0.0224
C29 |  | 10nF | 603 |  | Select by System | CL05B103KB5NNNC | Samsung Electro-Mechanics | 0402 | 10nF 50V X7R ±10% 0402 Multilayer Ceramic Capacitors MLCC - SMD/SMT ROHS | Multilayer Ceramic Capacitors MLCC - SMD/SMT |  | C15195 | https://jlcpcb.com/partdetail/15869-CL05B103KB5NNNC/C15195 | Basic | 2 | 2 JLCPCB | 0.0032
C33,C34,C35,C36,C38 |  | 2.2uF | 603 |  | Select by Customer | CL10A225KO8NNNC | Samsung Electro-Mechanics | 0603 | 16V 2.2uF X5R ±10% 0603 Multilayer Ceramic Capacitors MLCC - SMD/SMT ROHS | Multilayer Ceramic Capacitors MLCC - SMD/SMT |  | C23630 | https://jlcpcb.com/partdetail/24366-CL10A225KO8NNNC/C23630 | Basic | 10 | 10 JLCPCB | 0.074
C37,C39 |  | 680uF80V | CAPPRD750W85D1600H2700 |  | Select by System | EEUFS1K681 | PANASONIC | 插件,D16xL25mm | -40℃~+105℃ 10000hrs@105℃ 16mm 2.5A@100kHz 25mm 25mΩ@100kHz 680uF 7.5mm 80V ±20% 插件,D16xL25mm Aluminum Electrolytic Capacitors - Leaded ROHS | Aluminum Electrolytic Capacitors - Leaded |  | C407989 | https://jlcpcb.com/partdetail/PANASONIC-EEUFS1K681/C407989 | Extended | 4 | 4 JLCPCB | 5.532
D1 |  | SS1880V1A | DIOM5227X270N |  | Select by System | SS18 | YFW | SMA(DO-214AC) | -55℃~+150℃ 1A 300uA@80V 40A 700mV@1A 80V Independent SMA(DO-214AC) Schottky Diodes ROHS | Schottky Diodes |  | C2898405 | https://jlcpcb.com/partdetail/YFW-SS18/C2898405 | Extended | 20 | 20 JLCPCB | 0.468
D2 |  | LEDA | 603 |  | Select by System | GL0603UR01 | Gui guang light | 0603 | -40℃~+85℃ 120mcd 120° 2.4V 20mA 620nm~625nm Discrete Diode Red Top-mount Water Clear 0603 LED Indication - Discrete ROHS |  |  | C51933292 | https://jlcpcb.com/partdetail/Gui_guanglight-GL0603UR01/C51933292 | Extended | 20 | 20 JLCPCB | 0.062
D3 |  | LEDB | 603 |  | Select by System | F.0603.00025/P2-0603G1TS2-06T-002 | TUOZHAN | 0603 | -40℃~+85℃ 120° 2.6V~2.9V 230mcd 30mA 517nm 520nm~525nm 90mW Discrete Diode Emerald Green 0603 LED Indication - Discrete ROHS | LED Indication - Discrete |  | C7496818 | https://jlcpcb.com/partdetail/C7496818 | Extended | 20 | 20 JLCPCB | 0.084
D4 |  | LEDC | 603 |  | Select by System | GL0603UB01 | Gui guang light | 0603 | -40℃~+85℃ 120° 2.9V 20mA 460nm~469nm 72mcd Blue Discrete Diode Top-mount Water Clear 0603 LED Indication - Discrete ROHS |  |  | C51933294 | https://jlcpcb.com/partdetail/Gui_guanglight-GL0603UB01/C51933294 | Extended | 20 | 20 JLCPCB | 0.068
D5 |  | USBLC6-2SC6Y | SOT95P280X145-6N |  | Select by System | USBLC6-2SC6Y | STMicroelectronics | SOT-23-6L | -40℃~+150℃ 10nA 12V 2 2.5pF 6V ESD Unidirectional SOT-23-6L ESD and Surge Protection (TVS/ESD) ROHS | ESD And Surge Protection (TVS/ESD) |  | C2969755 | https://jlcpcb.com/partdetail/STMicroelectronics-USBLC62SC6Y/C2969755 | Extended | 5 | 5 JLCPCB | 1.351
D6 |  | D_Zener | SOD3716X135N |  | Select by System | MMSZ4684 | amsem | SOD-123 | 1 Independent 3.135V~3.465V 3.3V 500mW 7.5uA@1.5V SOD-123 Zener Diodes ROHS | Zener Diodes |  | C7529058 | https://jlcpcb.com/partdetail/amsem-MMSZ4684/C7529058 | Extended | 15 | 15 JLCPCB | 0.354
D7 |  | SMAJ5.0A-E3_61 | DIOM5127X229N |  | Select by System | SMAJ5.0A-E3/61 | Vishay Intertech | DO-214AC(SMA) | 400W 43.5A 5V 6.4V 9.2V TVS DO-214AC(SMA) ESD and Surge Protection (TVS/ESD) ROHS | ESD And Surge Protection (TVS/ESD) |  | C89363 | https://jlcpcb.com/partdetail/VishayIntertech-SMAJ5_0A_E361/C89363 | Extended | 6 | 6 JLCPCB | 0.7272
IC1 |  | TCAN330DCNT | SOT65P280X145-8N |  | Select by System | TCAN330DCNT | Texas Instruments | SOT-23-8 | -40℃~+125℃ 1Mbps 2.5mA 3V~3.6V 60mA CAN Transceiver SOT-23-8 CAN Transceivers ROHS | CAN Transceivers |  | C2671056 | https://jlcpcb.com/partdetail/TexasInstruments-TCAN330DCNT/C2671056 | Extended | 2 | 2 JLCPCB | 4.91
J2 |  | USB_C_Receptacle_USB2.0_16P | USB_C_Receptacle_GCT_USB4105-xx-A_16P_TopMnt_Horizontal |  | Select by System | USB4105-GF-A-060 | Global Connector Technology | SMD | -40℃~+85℃ 1 12P 48V 5A Black Female Surface Mount, Right Angle Type-C USB 2.0 SMD USB Connectors ROHS | USB Connectors |  | C3025063 | https://jlcpcb.com/partdetail/3554049-USB4105_GF_A060/C3025063 | Extended | 2 | 2 JLCPCB | 2.0352
L1 |  | 22uH1.6A | INDM7676X355N |  | Select by System | FNR5040S220MT | cjiang (Changjiang Microelectronics Tech) | SMD,5x5mm | 1.6A 1.8A 168mΩ 22uH Magnetic Shielded Inductor ±20% SMD,5x5mm Power Inductors ROHS | Power Inductors |  | C167971 | https://jlcpcb.com/partdetail/179354-FNR5040S220MT/C167971 | Extended | 5 | 5 JLCPCB | 0.3045
L2 |  | 100MHz/1kR | 603 |  | Select by System | MPZ1608S102ATA00 | TDK | 0603 | -55℃~+125℃ 1 1kΩ@100MHz 300mΩ 800mA ±25% 0603 Ferrite Beads ROHS | Ferrite Beads |  | C76814 | https://jlcpcb.com/partdetail/TDK-MPZ1608S102ATA00/C76814 | Extended | 20 | 20 JLCPCB | 0.264
Q10,Q11,Q12,Q7,Q8,Q9 |  | STL90N6F7 | STL90N6F7_Thermal_Vias |  | Select by System | STL90N6F7 | STMicroelectronics | PowerFLAT(5x6) | -55℃~+175℃ 1 N-channel 1.6nF 25nC@10V 4V 5.4mΩ@10V 60V 66pF 90A 94W N-Channel PowerFLAT(5x6) MOSFETs ROHS | MOSFETs |  | C221506 | https://jlcpcb.com/partdetail/STMicroelectronics-STL90N6F7/C221506 | Extended | 12 | 12 JLCPCB | 12.4992
R6 |  | 5k6 | RESC1607X60N |  | Select by Customer | 0603WAF5601T5E | UNI-ROYAL(Uniroyal Elec) | 0603 | -55℃~+155℃ 100mW 5.6kΩ 75V Thick Film Resistor ±1% ±100ppm/℃ 0603 Chip Resistor - Surface Mount ROHS | Chip Resistor - Surface Mount |  | C23189 | https://jlcpcb.com/partdetail/23916-0603WAF5601T5E/C23189 | Basic | 2 | 2 JLCPCB | 0.0028
R10,R12,R14 |  | 91k | 603 |  | Select by System | FRC0603F9102TS | FOJAN | 0603 | -55℃~+155℃ 100mW 75V 91kΩ Thick Film Resistor ±1% ±100ppm/℃ 0603 Chip Resistor - Surface Mount ROHS | Chip Resistor - Surface Mount |  | C2907077 | https://jlcpcb.com/partdetail/FOJAN-FRC0603F9102TS/C2907077 | Extended | 20 | 20 JLCPCB | 0.022
R11,R13,R15 |  | 4k7 | 603 |  | Select by Customer | 0603WAF4701T5E | UNI-ROYAL(Uniroyal Elec) | 0603 | -55℃~+155℃ 100mW 4.7kΩ 75V Thick Film Resistor ±1% ±100ppm/℃ 0603 Chip Resistor - Surface Mount ROHS | Chip Resistor - Surface Mount |  | C23162 | https://jlcpcb.com/partdetail/23889-0603WAF4701T5E/C23162 | Basic | 6 | 6 JLCPCB | 0.0078
R16,R17,R26,R5,R8,R9 |  | 10k | 603 |  | Select by Customer | 0603WAF1002T5E | UNI-ROYAL(Uniroyal Elec) | 0603 | -55℃~+155℃ 100mW 10kΩ 75V Thick Film Resistor ±1% ±100ppm/℃ 0603 Chip Resistor - Surface Mount ROHS | Chip Resistor - Surface Mount |  | C25804 | https://jlcpcb.com/partdetail/26547-0603WAF1002T5E/C25804 | Basic | 14 | 14 JLCPCB | 0.0154
R22 |  | 10k | 603 |  | Select by Customer | 0603WAF1002T5E | UNI-ROYAL(Uniroyal Elec) | 0603 | -55℃~+155℃ 100mW 10kΩ 75V Thick Film Resistor ±1% ±100ppm/℃ 0603 Chip Resistor - Surface Mount ROHS | Chip Resistor - Surface Mount |  | C25804 | https://jlcpcb.com/partdetail/26547-0603WAF1002T5E/C25804 | Basic | 14 | 14 JLCPCB | 0.0154
R18,R19,R20 |  | 330R | 603 |  | Select by Customer | 0603WAF3300T5E | UNI-ROYAL(Uniroyal Elec) | 0603 | -55℃~+155℃ 100mW 330Ω 75V Thick Film Resistor ±1% ±100ppm/℃ 0603 Chip Resistor - Surface Mount ROHS | Chip Resistor - Surface Mount |  | C23138 | https://jlcpcb.com/partdetail/23865-0603WAF3300T5E/C23138 | Basic | 6 | 6 JLCPCB | 0.0096
R21,RGA3,RGA4,RGB3,RGB4,RGC3,RGC4 |  | 0ohm | RESC1508X55N |  | Select by Customer | 0603WAF0000T5E | UNI-ROYAL(Uniroyal Elec) | 0603 | -55℃~+155℃ 0Ω 100mW 75V Thick Film Resistor ±1% 0603 Chip Resistor - Surface Mount ROHS | Chip Resistor - Surface Mount | 1.There may be multiple types of parts, but one type of part has been matched. Please check.; | C21189 | https://jlcpcb.com/partdetail/21903-0603WAF0000T5E/C21189 | Basic | 14 | 14 JLCPCB | 0.021
R23 |  | 3.3k | 603 |  | Select by Customer | 0603WAF3301T5E | UNI-ROYAL(Uniroyal Elec) | 0603 | -55℃~+155℃ 100mW 3.3kΩ 75V Thick Film Resistor ±1% ±100ppm/℃ 0603 Chip Resistor - Surface Mount ROHS | Chip Resistor - Surface Mount |  | C22978 | https://jlcpcb.com/partdetail/23705-0603WAF3301T5E/C22978 | Basic | 2 | 2 JLCPCB | 0.0038
R24,R4 |  | 100k | 603 |  | Select by Customer | 0603WAF1003T5E | UNI-ROYAL(Uniroyal Elec) | 0603 | -55℃~+155℃ 100kΩ 100mW 75V Thick Film Resistor ±1% ±100ppm/℃ 0603 Chip Resistor - Surface Mount ROHS | Chip Resistor - Surface Mount |  | C25803 | https://jlcpcb.com/partdetail/26546-0603WAF1003T5E/C25803 | Basic | 4 | 4 JLCPCB | 0.0072
R25,R28,R7 |  | 1k | 603 |  | Select by Customer | 0603WAF1001T5E | UNI-ROYAL(Uniroyal Elec) | 0603 | -55℃~+155℃ 100mW 1kΩ 75V Thick Film Resistor ±1% ±100ppm/℃ 0603 Chip Resistor - Surface Mount ROHS | Chip Resistor - Surface Mount |  | C21190 | https://jlcpcb.com/partdetail/21904-0603WAF1001T5E/C21190 | Basic | 6 | 6 JLCPCB | 0.0096
R27 |  | 120R | 603 |  | Select by Customer | 0603WAF1200T5E | UNI-ROYAL(Uniroyal Elec) | 0603 | -55℃~+155℃ 100mW 120Ω 75V Thick Film Resistor ±1% ±100ppm/℃ 0603 Chip Resistor - Surface Mount ROHS | Chip Resistor - Surface Mount |  | C22787 | https://jlcpcb.com/partdetail/23514-0603WAF1200T5E/C22787 | Basic | 2 | 2 JLCPCB | 0.0028
RSENSE_A4,RSENSE_A5,RSENSE_B4,RSENSE_B5,RSENSE_C4,RSENSE_C5 |  | 2mohm | RESC6432X80N |  | Unconfirmed | CRF2512-FZ-R002ELF | BOURNS | 2512 | -55℃~+170℃ 2W 2mΩ ±1% ±50ppm/℃ 2512 Chip Resistor - Surface Mount ROHS | Chip Resistor - Surface Mount | 1.There may be multiple types of parts, but one type of part has been matched. Please check.; | C4198046 | https://jlcpcb.com/partdetail/BOURNS-CRF2512_FZR002ELF/C4198046 | Extended | 12 | 12 JLCPCB | 4.404
SW1,SW2 |  | SW_SPDT | SW_SPDT_PCM12 |  | Select by System | PCM12SMTR | C&K | SMD | -20℃~+85℃ 6V PC Pin Rectangular Columnar SPDT Surface Mount,Vertical SMD Slide Switches ROHS | Slide Switches |  | C221841 | https://jlcpcb.com/partdetail/CK-PCM12SMTR/C221841 | Extended | 4 | 4 JLCPCB | 4.9612
TH1 |  | ERT-J1VG103FA | 603 |  | Select by System | ERTJ1VG103FA | PANASONIC | 0603 | -40℃~+125℃ 0.8mm 0.8mm 1.6mm 100mW 10kΩ 3380K 3435K 3mW/℃ ±1% ±1% 0603 NTC Thermistors ROHS | NTC Thermistors |  | C153011 | https://jlcpcb.com/partdetail/PANASONIC-ERTJ1VG103FA/C153011 | Extended | 5 | 5 JLCPCB | 0.4255
U1 |  | DRV8323RSRGZR | QFN50P700X700X100-49N |  | Select by System | DRV8323RSRGZT | Texas Instruments | VQFN-48-EP(7x7) | -40℃~+125℃ 1A、2A SPI VQFN-48-EP(7x7) Gate Drivers ROHS | Brushless DC (BLDC) Motor Driver |  | C2653553 | https://jlcpcb.com/partdetail/TexasInstruments-DRV8323RSRGZT/C2653553 | Extended | 2 | 2 JLCPCB | 11.355
U2 |  | ME6211C33M5 | SOT-23-5 |  | Select by System | ME6211C33M5G-N | MICRONE(Nanjing Micro One Elec) | SOT-23-5 | -40℃~+150℃ 1 120mV@(100mA) 3.3V 500mA 50uVrms 60uA 6V 70dB@(1kHz) Fixed Over Current Protection、Enable、Short Circuit Protection Positive SOT-23-5 Voltage Regulators - Linear, Low Drop Out (LDO) Regulators ROHS | Voltage Regulators - Linear, Low Drop Out (LDO) Regulators |  | C82942 | https://jlcpcb.com/partdetail/84106-ME6211C33M5GN/C82942 | Extended | 6 | 6 JLCPCB | 0.2976
U3 |  | STM32G431CBU6 | QFN50P700X700X60-49N |  | Select by System | STM32G431CBU6 | STMicroelectronics | UFQFPN-48(7x7) | -40℃~+85℃ 1.71V~3.6V 128KB 12bit 12bit 170MHz 32 Bit 32KB 42 ARM Cortex-M4F Built-in FLASH UFQFPN-48(7x7) Microcontrollers (MCU/MPU/SOC) ROHS | Microcontrollers (MCU/MPU/SOC) |  | C529356 | https://jlcpcb.com/partdetail/STMicroelectronics-STM32G431CBU6/C529356 | Extended | 2 | 2 JLCPCB | 10.8006
Y1 |  | ECS-80-20-5PX-TR | XTAL_ECS-80-20-5PX-TR |  | Select by System | ECS-80-20-5PXDU-TR | ECS | HC-49S-SMD | -55℃~+125℃ 20pF 60Ω 8MHz ±100ppm ±30ppm HC-49S-SMD Crystals ROHS | Crystals |  | C2441302 | https://jlcpcb.com/partdetail/ECS-ECS_80_20_5PXDUTR/C2441302 | Extended | 2 | 2 JLCPCB | 1.7084
Z1,Z2 |  | KDZLVTR56 | KDZLVTR56 |  | Select by System | KDZLVTR56 | ROHM Semicon | SOD-123F | 1 Independent 1W 30Ω 53V~60V 56V 5uA@43V 60Ω SOD-123F Zener Diodes ROHS | Zener Diodes |  | C3737443 | https://jlcpcb.com/partdetail/ROHMSemicon-KDZLVTR56/C3737443 | Extended | 6 | 6 JLCPCB | 1.8654
J1,J5 |  | BM04B-GHS-TBT_LF__SN__N_ | JST_BM04B-GHS-TBT_LF__SN__N_ |  | Select by System | BM04B-GHS-TBT(LF)(SN)(N) | JST | SMD,P=1.25mm | -25℃~+85℃ 1 1.25mm 1A 1x4P 4 4.05mm 4.32mm 4P 50V 8.25mm Auxiliary Solder Pin GH PA9T Phosphor bronze Surface Mount,Vertical Tin UL94V-0 White SMD,P=1.25mm Wire To Board Connector ROHS |  |  | C2983876 | https://jlcpcb.com/partdetail/JST-BM04B_GHS_TBT_LF_SN_N/C2983876 | Extended | 4 | 0 JLCPCB | 0
BATT+1,BATT-1 |  | power_pad_smd | Power_pad_smd |  | No matches | No Part Selected
C11 |  | 0.1uF6.3V | CAPC2012X140N |  | No matches | No Part Selected
J3 |  | Conn_01x02_Socket | TerminalBlock_MaiXu_MX126-5.0-02P_1x02_P5.00mm |  | No matches | No Part Selected
J4 |  | Conn_01x04_Pin | PinHeader_1x04_P1.00mm_Vertical |  | No matches | No Part Selected

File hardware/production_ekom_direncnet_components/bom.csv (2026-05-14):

Designator | Footprint | Quantity | Value | LCSC Part #
BATT+1, POWER_PAD_SMD1 | Power_pad_smd | 2 | power_pad_smd
C10 | 805 | 1 | 22uF 16V
C11 | CAPC2012X140N | 1 | 0.1uF 6.3V
C12 | CAPC1608X90N | 1 | 1uF 16V
C13 | CAPC1608X90N | 1 | 0.1 uF 100V
C14 | CAPPRD500W50D630H1120 | 1 | 22uF 100V
C15, C16, C17 | 603 | 3 | 10nF
C18, C32 | 603 | 2 | 1uF
C19, C20, C28 | 603 | 3 | 1uF | C52923
C21 | 603 | 1 | 4u7 | C19666
C22, C23, C24, C26, C31 | 805 | 5 | 100nF | C1525
C25, C27 | 805 | 2 | 33pF
C29 | 603 | 1 | 10nF | C15195
C30 | 805 | 1 | 100nF
C33, C34, C35, C36, C38 | 603 | 5 | 2.2uF
C37, C39 | 80ZLJ680MGC18X25 | 2 | 680uF 80V
C6, C9 | 805 | 2 | 47nF 100V
C7 | 603 | 1 | 0.1uF 16V
C8 | 603 | 1 | 1uF 6.3V
D1 | D_SMA | 1 | 80V 1A
D2 | 603 | 1 | LEDA
D3 | 603 | 1 | LEDB
D4 | 603 | 1 | LEDC
D5 | SOT95P280X145-6N | 1 | USBLC6-2SC6Y
D6 | SOD3716X135N | 1 | D_Zener
IC1 | SOT65P280X145-8N | 1 | TCAN330DCNT
J1, J5 | JST_BM04B-GHS-TBT_LF__SN__N_ | 2 | BM04B-GHS-TBT_LF__SN__N_
J2 | USB_C_Receptacle_GCT_USB4105-xx-A_16P_TopMnt_Horizontal | 1 | USB_C_Receptacle_USB2.0_16P
J3 | TerminalBlock_MaiXu_MX126-5.0-02P_1x02_P5.00mm | 1 | Conn_01x02_Socket
J4 | PinHeader_1x04_P1.00mm_Vertical | 1 | Conn_01x04_Pin
L1 | INDM7676X355N | 1 | 22uH 1.6A | DR73-220-R
L2 | 603 | 1 | 100MHz / 1kR | C26443
Q10, Q11, Q12, Q7, Q8, Q9 | STL90N6F7_Thermal_Vias | 6 | STL90N6F7
R10, R12, R14 | 603 | 3 | 91k
R11, R13, R15 | 603 | 3 | 4k7
R16, R17, R26, R5, R8, R9 | 603 | 6 | 10k
R18, R19, R20 | 603 | 3 | 330R
R21, RGA3, RGA4, RGB3, RGB4, RGC3, RGC4 | RESC1508X55N | 7 | 0ohm
R22 | 603 | 1 | 10k | C25744
R23 | 603 | 1 | 3.3k
R24, R4 | 603 | 2 | 100k
R25, R28, R7 | 603 | 3 | 1k
R27 | 603 | 1 | 120R
R6 | RESC1607X60N | 1 | 5k6
RSENSE_A4, RSENSE_A5, RSENSE_B4, RSENSE_B5, RSENSE_C4, RSENSE_C5 | RESC6432X80N | 6 | 2mohm
SW1, SW2 | SW_SPDT_PCM12 | 2 | SW_SPDT
TH1 | 603 | 1 | ERT-J1VG103FA
U1 | QFN50P700X700X100-49N | 1 | DRV8323RSRGZR
U2 | SOT-23-5 | 1 | ME6211C33M5
U3 | QFN50P700X700X60-49N | 1 | STM32G431CBU6
Y1 | XTAL_ECS-80-20-5PX-TR | 1 | ECS-80-20-5PX-TR

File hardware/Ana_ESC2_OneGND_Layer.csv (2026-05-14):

Reference | Qty | Value | DNP | Exclude from BOM | Exclude from Board | Footprint | Datasheet
Batt+1,Power_Pad_SMD1 | 2 | power_pad_smd |  |  |  | Pads:Power_pad_smd
C1,C2,C3 | 3 | 2.2uF | DNP | Excluded from BOM | Excluded from board | Capacitor_SMD:C_0805_2012Metric_Pad1.18x1.45mm_HandSolder | ~
C4,C5 | 2 | 680uF 80V | DNP | Excluded from BOM | Excluded from board | ul_80ZLJ680MGC18X25:CAP_YX_18X25_RUB | 80ZLJ680MGC18X25
C6,C9 | 2 | 47nF 100V |  |  |  | Capacitor_SMD:C_0805_2012Metric_Pad1.18x1.45mm_HandSolder | https://content.kemet.com/datasheets/KEM_C1090_X7R_ESD.pdf
C7 | 1 | 0.1uF 16V |  |  |  | Capacitor_SMD:C_0603_1608Metric_Pad1.08x0.95mm_HandSolder
C8 | 1 | 1uF 6.3V |  |  |  | Capacitor_SMD:C_0603_1608Metric_Pad1.08x0.95mm_HandSolder | https://www.direnc.net/1uf-16v-10-x5r-603-smd-kondansator
C10 | 1 | 22uF 16V |  |  |  | Capacitor_SMD:C_0805_2012Metric_Pad1.18x1.45mm_HandSolder
C11 | 1 | 0.1uF 6.3V |  |  |  | 08056D104KAT2A:CAPC2012X140N
C12 | 1 | 1uF 16V |  |  |  | C0603C105K4RACTU:CAPC1608X90N
C13 | 1 | 0.1 uF 100V |  |  |  | CL10B104KC8NNNC:CAPC1608X90N
C14 | 1 | 22uF 100V |  |  |  | ECA2AM220B:CAPPRD500W50D630H1120
C15,C16,C17,C29 | 4 | 10nF |  |  |  | Capacitor_SMD:C_0603_1608Metric_Pad1.08x0.95mm_HandSolder | ~
C18,C32 | 2 | 1uF |  |  |  | Capacitor_SMD:C_0603_1608Metric | ~
C19,C20 | 2 | 1u |  |  |  | Capacitor_SMD:C_0603_1608Metric_Pad1.08x0.95mm_HandSolder | https://www.direnc.net/1uf-50v-10-603-smd-kondansator
C21 | 1 | 4u7 |  |  |  | Capacitor_SMD:C_0603_1608Metric_Pad1.08x0.95mm_HandSolder | ~
C22,C23,C24,C30 | 4 | 100nF |  |  |  | Capacitor_SMD:C_0603_1608Metric_Pad1.08x0.95mm_HandSolder | direnc.net,https://www.direnc.net/100nf50v-805-kilif
C25,C27 | 2 | 33pF |  |  |  | Capacitor_SMD:C_0805_2012Metric_Pad1.18x1.45mm_HandSolder | ~
C26 | 1 | 100n |  |  |  | Capacitor_SMD:C_0603_1608Metric_Pad1.08x0.95mm_HandSolder | direnc.net
C28 | 1 | 1uF |  |  |  | Capacitor_SMD:C_0603_1608Metric_Pad1.08x0.95mm_HandSolder | direnc.net
C31 | 1 | 100nF |  |  |  | Capacitor_SMD:C_0805_2012Metric_Pad1.18x1.45mm_HandSolder | direnc.net
C33,C34 | 2 | 2.2uF |  |  |  | Capacitor_SMD:C_0603_1608Metric | ~
C35,C36,C38 | 3 | 2.2uF |  |  |  | Capacitor_SMD:C_1206_3216Metric_Pad1.33x1.80mm_HandSolder | ~
C37,C39 | 2 | 680uF 80V |  |  |  | ul_80ZLJ680MGC18X25:80ZLJ680MGC18X25 | 80ZLJ680MGC18X25
D1 | 1 | 80V 1A |  |  |  | Diode_SMD:D_SMA | https://www.smc-diodes.com/propdf/SS12-SS110%20N0229%20REV.C.pdf
D2 | 1 | LEDA |  |  |  | LED_SMD:LED_0603_1608Metric_Pad1.05x0.95mm_HandSolder | ~
D3 | 1 | LEDB |  |  |  | LED_SMD:LED_0603_1608Metric_Pad1.05x0.95mm_HandSolder | ~
D4 | 1 | LEDC |  |  |  | LED_SMD:LED_0603_1608Metric_Pad1.05x0.95mm_HandSolder | ~
D5 | 1 | USBLC6-2SC6Y |  |  |  | SOT95P280X145-6N | https://www.st.com/resource/en/datasheet/usblc6-2sc6y.pdf
D6 | 1 | D_Zener |  |  |  | LIB_MMSZ4684-13P:SOD3716X135N | ~
H1,H2,H3,H4 | 4 | MountingHole |  | Excluded from BOM |  | MountingHole:MountingHole_3.2mm_M3 | ~
IC1 | 1 | TCAN330DCNT |  |  |  | LIB_TCAN330DCNT:SOT65P280X145-8N | https://www.ti.com/lit/gpn/TCAN330
J1,J5 | 2 | BM04B-GHS-TBT_LF__SN__N_ |  |  |  | ul_BM04B-GHS-TBT-LF-SN-N-:JST_BM04B-GHS-TBT_LF__SN__N_ | http://www.jst-mfg.com/product/pdf/eng/eGH.pdf
J2 | 1 | USB_C_Receptacle_USB2.0_16P |  |  |  | Connector_USB:USB_C_Receptacle_GCT_USB4105-xx-A_16P_TopMnt_Horizontal | https://www.usb.org/sites/default/files/documents/usb_type-c.zip
J3 | 1 | Conn_01x02_Socket |  |  |  | TerminalBlock:TerminalBlock_MaiXu_MX126-5.0-02P_1x02_P5.00mm | ~
J4 | 1 | Conn_01x04_Pin |  |  |  | Connector_PinHeader_1.00mm:PinHeader_1x04_P1.00mm_Vertical | ~
L1 | 1 | 22uH 1.6A |  |  |  | DR73-220-R:INDM7676X355N
L2 | 1 | 100MHz / 1kR |  |  |  | Inductor_SMD:L_0603_1608Metric_Pad1.05x0.95mm_HandSolder | ~
Q1,Q2,Q3,Q4,Q5,Q6 | 6 | STB75NF75T4 | DNP | Excluded from BOM | Excluded from board | STB75NF75T4 | https://www.st.com/resource/en/datasheet/stb75nf75.pdf
Q7,Q8,Q9,Q10,Q11,Q12 | 6 | STL90N6F7 |  |  |  | STL90N6F7:STL90N6F7_Thermal_Vias | https://www.st.com/resource/en/datasheet/stl90n6f7.pdf
R1,R2,R3 | 3 | 47k | DNP | Excluded from BOM | Excluded from board | Resistor_SMD:R_0603_1608Metric_Pad0.98x0.95mm_HandSolder | ~
R4 | 1 | 100K |  |  |  | RC0603FR-07100KL:RESC1607X60N
R5,R8,R9 | 3 | 10K |  |  |  | RC0603FR-0710KL:RESC1607X60N
R6 | 1 | 5k6 |  |  |  | RC0603FR-073K3L:RESC1607X60N
R7 | 1 | 1k |  |  |  | RNCP0603FTD1K00:RESC1508X50N
R10,R12,R14 | 3 | 91k |  |  |  | Resistor_SMD:R_0603_1608Metric_Pad0.98x0.95mm_HandSolder
R11,R13,R15 | 3 | 4k7 |  |  |  | Resistor_SMD:R_0603_1608Metric_Pad0.98x0.95mm_HandSolder
R16,R17,R22,R26 | 4 | 10k |  |  |  | Resistor_SMD:R_0603_1608Metric_Pad0.98x0.95mm_HandSolder | ~
R18,R19,R20 | 3 | 330R |  |  |  | Resistor_SMD:R_0603_1608Metric_Pad0.98x0.95mm_HandSolder | ~
R21 | 1 | 0 ohm |  |  |  | RMCF0603ZT0R00:RESC1508X55N | ~
R23 | 1 | 3.3k |  |  |  | Resistor_SMD:R_0603_1608Metric_Pad0.98x0.95mm_HandSolder | ~
R24 | 1 | 100k |  |  |  | Resistor_SMD:R_0603_1608Metric_Pad0.98x0.95mm_HandSolder | ~
R25,R28 | 2 | R_Small |  |  |  | Resistor_SMD:R_0603_1608Metric_Pad0.98x0.95mm_HandSolder | ~
R27 | 1 | 120R |  |  |  | Resistor_SMD:R_0603_1608Metric_Pad0.98x0.95mm_HandSolder | ~
RGA1,RGA2,RGB1,RGB2,RGC1,RGC2 | 6 | 0ohm | DNP | Excluded from BOM | Excluded from board | RMCF0603ZT0R00:RESC1508X55N
RGA3,RGA4,RGB3,RGB4,RGC3,RGC4 | 6 | 0ohm |  |  |  | RMCF0603ZT0R00:RESC1508X55N
Rsense_A1,Rsense_A2,Rsense_A3,Rsense_B1,Rsense_B2,Rsense_B3,Rsense_C1,Rsense_C2,Rsense_C3 | 9 | 3mohm | DNP | Excluded from BOM | Excluded from board | CSNL2512FT3L00:RESC6331X75N
Rsense_A4,Rsense_A5,Rsense_B4,Rsense_B5,Rsense_C4,Rsense_C5 | 6 | 2mohm |  |  |  | CRF2512-FZ-R002ELF:RESC6432X80N
SW1,SW2 | 2 | SW_SPDT |  |  |  | Button_Switch_SMD:SW_SPDT_PCM12 | ~
TH1 | 1 | ERT-J1VG103FA |  |  |  | Resistor_SMD:R_0603_1608Metric | ~
U1 | 1 | DRV8323RSRGZR |  |  |  | DRV8323RSRGZR:QFN50P700X700X100-49N | kicad-embed://drv8323.pdf
U2 | 1 | ME6211C33M5 |  |  |  | Package_TO_SOT_SMD:SOT-23-5 | https://www.lcsc.com/datasheet/lcsc_datasheet_2304140030_MICRONE-Nanjing-Micro-One-Elec-ME6211C33R5G_C235316.pdf
U3 | 1 | STM32G431CBU6 |  |  |  | STM32G431CBU6:QFN50P700X700X60-49N
Y1 | 1 | ECS-80-20-5PX-TR |  |  |  | ECS-80-20-5PX-TR:XTAL_ECS-80-20-5PX-TR

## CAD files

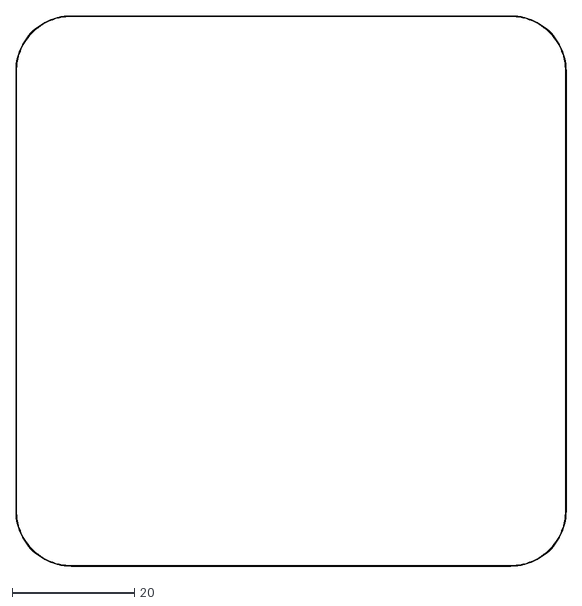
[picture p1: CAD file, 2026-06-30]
hardware/Stencil/Ana_ESC2_OneGND_Layer-Edge_Cuts.dxf
90.1 x 90.1

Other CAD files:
hardware/Stencil/Ana_ESC2_OneGND_Layer-F_Mask.dxf

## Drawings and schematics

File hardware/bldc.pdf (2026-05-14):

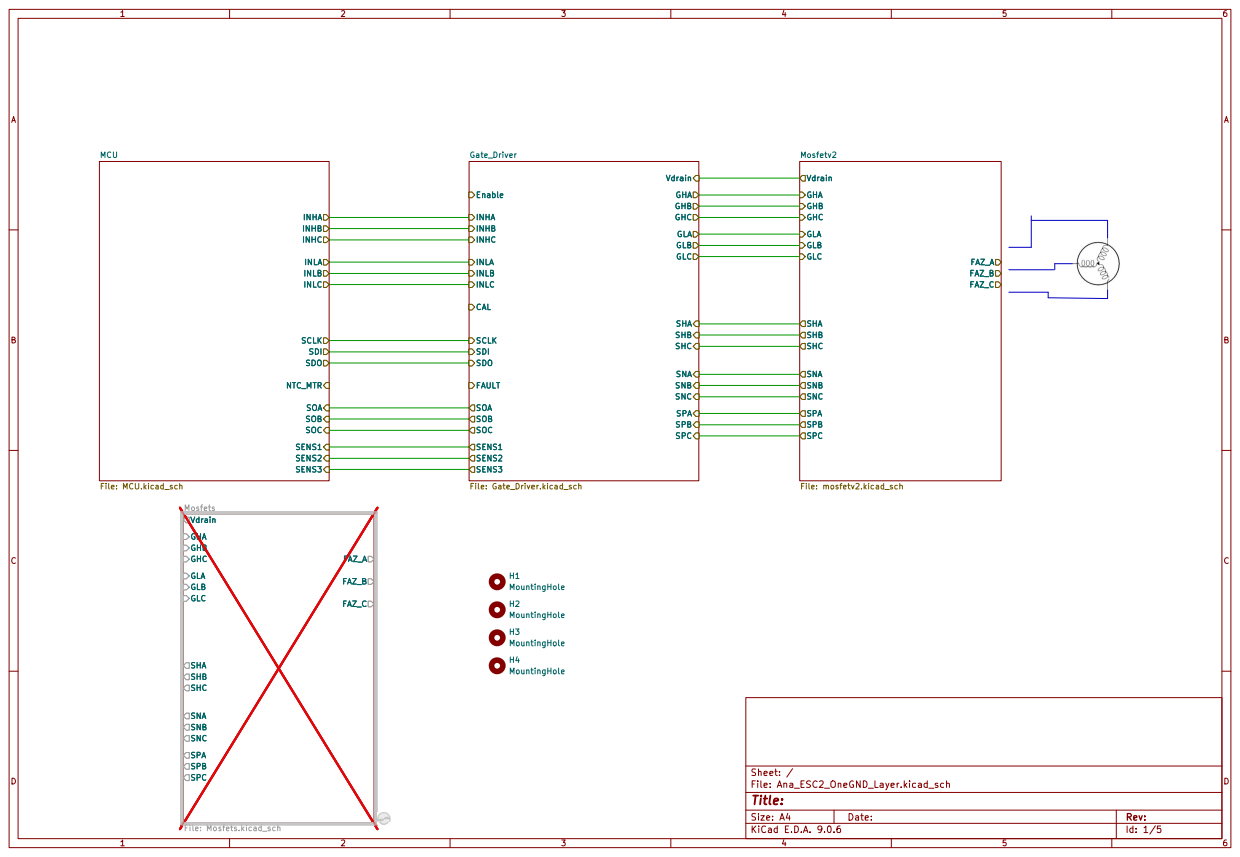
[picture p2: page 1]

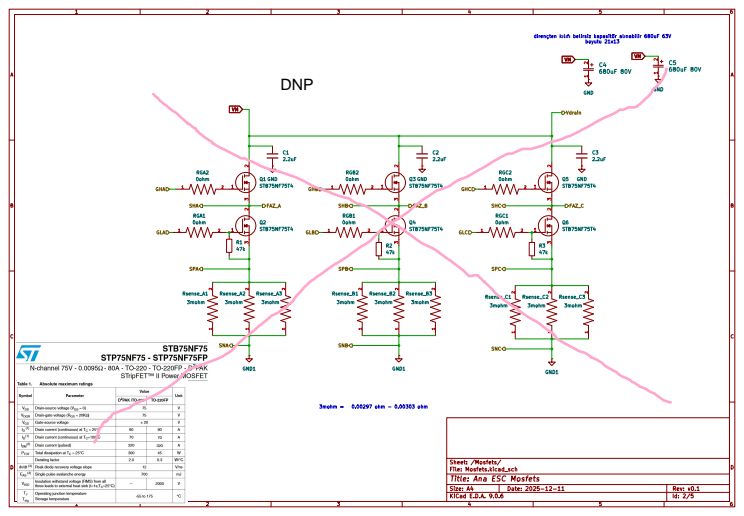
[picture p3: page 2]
DNP

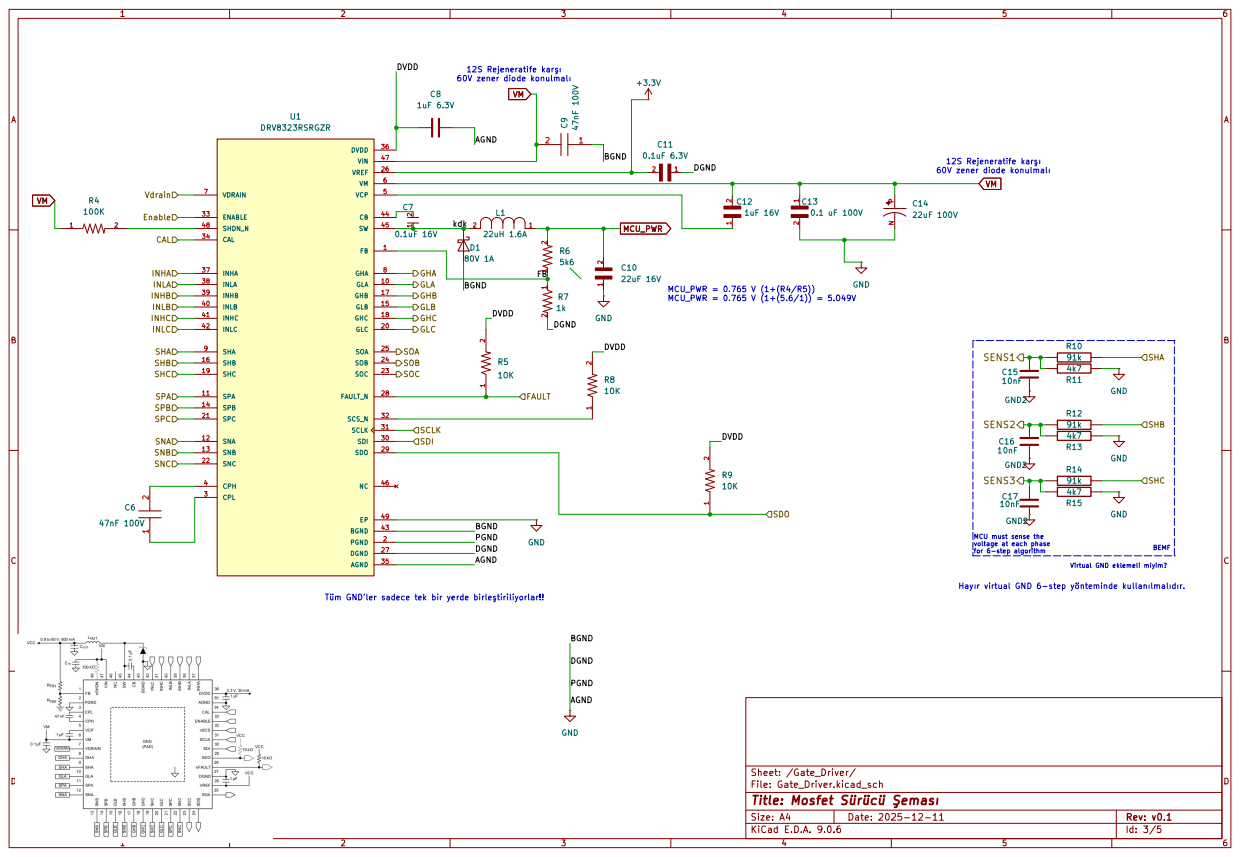
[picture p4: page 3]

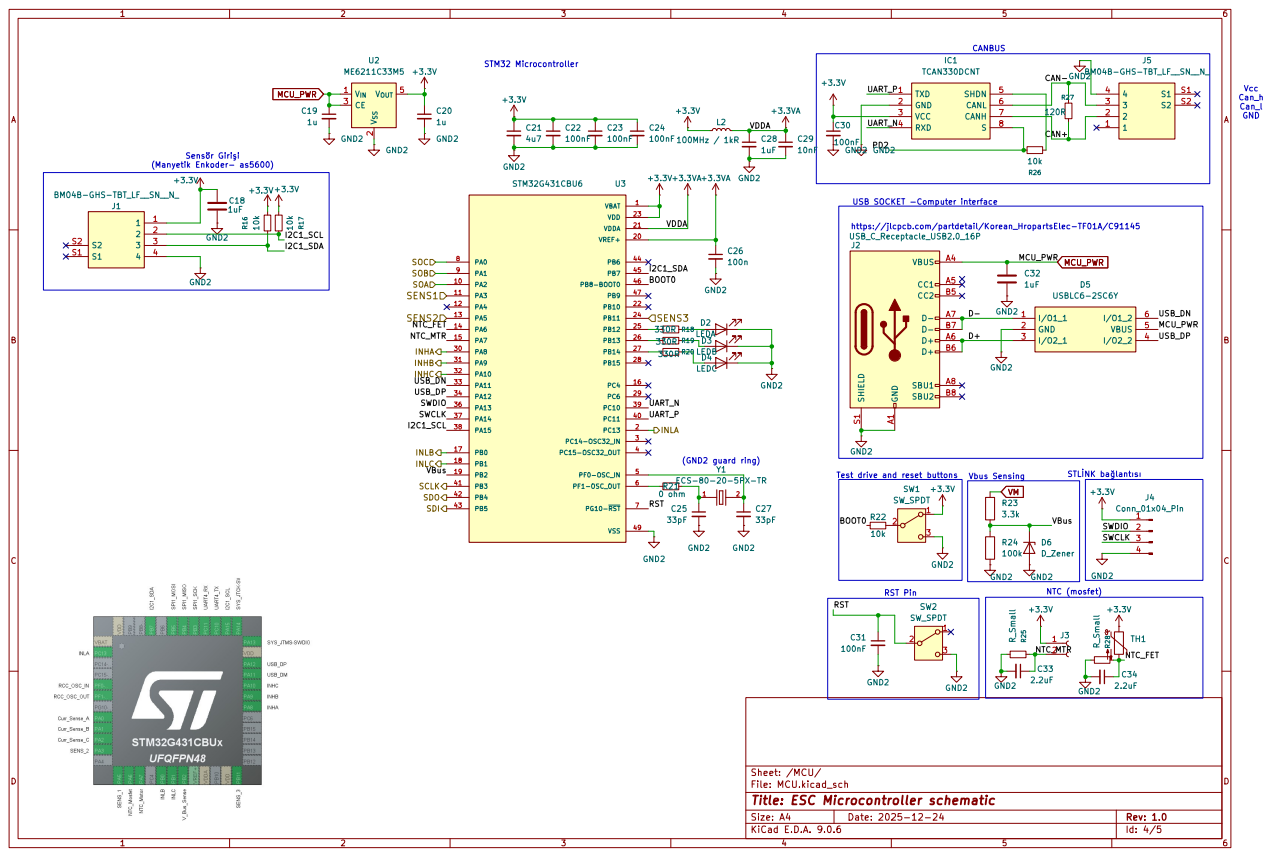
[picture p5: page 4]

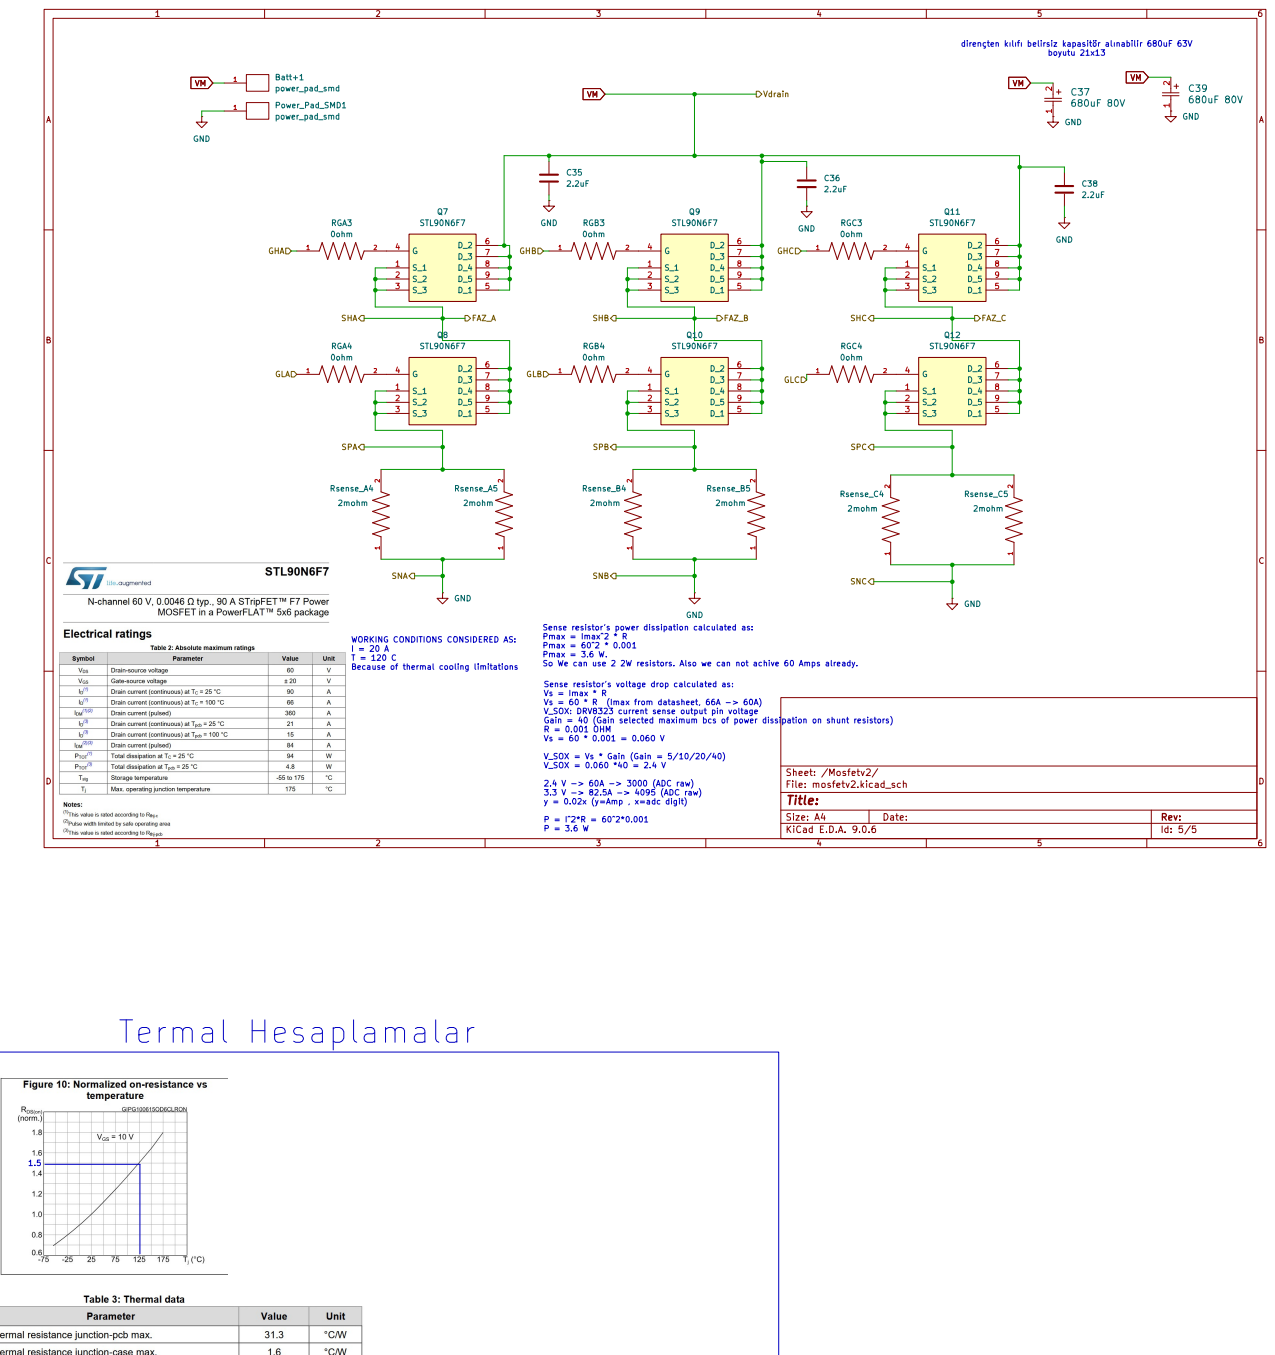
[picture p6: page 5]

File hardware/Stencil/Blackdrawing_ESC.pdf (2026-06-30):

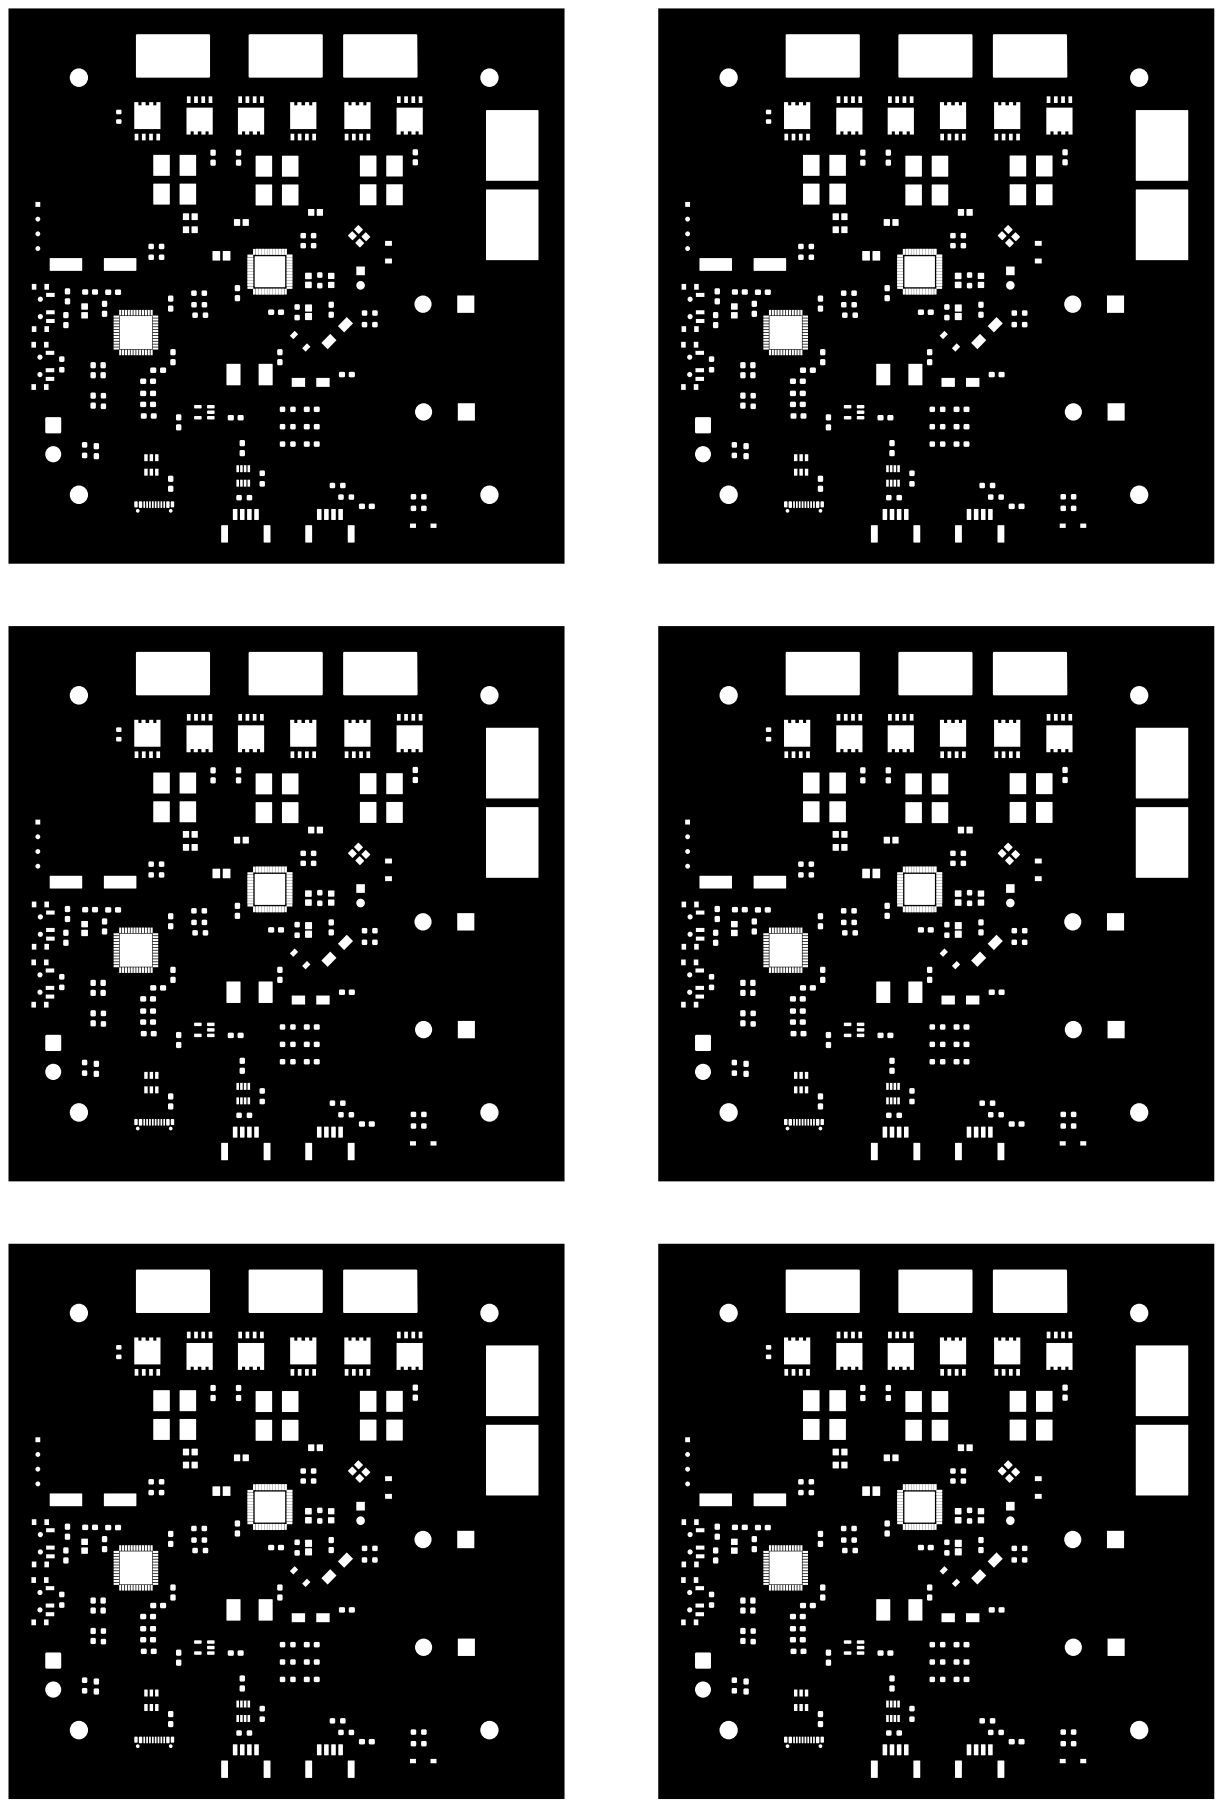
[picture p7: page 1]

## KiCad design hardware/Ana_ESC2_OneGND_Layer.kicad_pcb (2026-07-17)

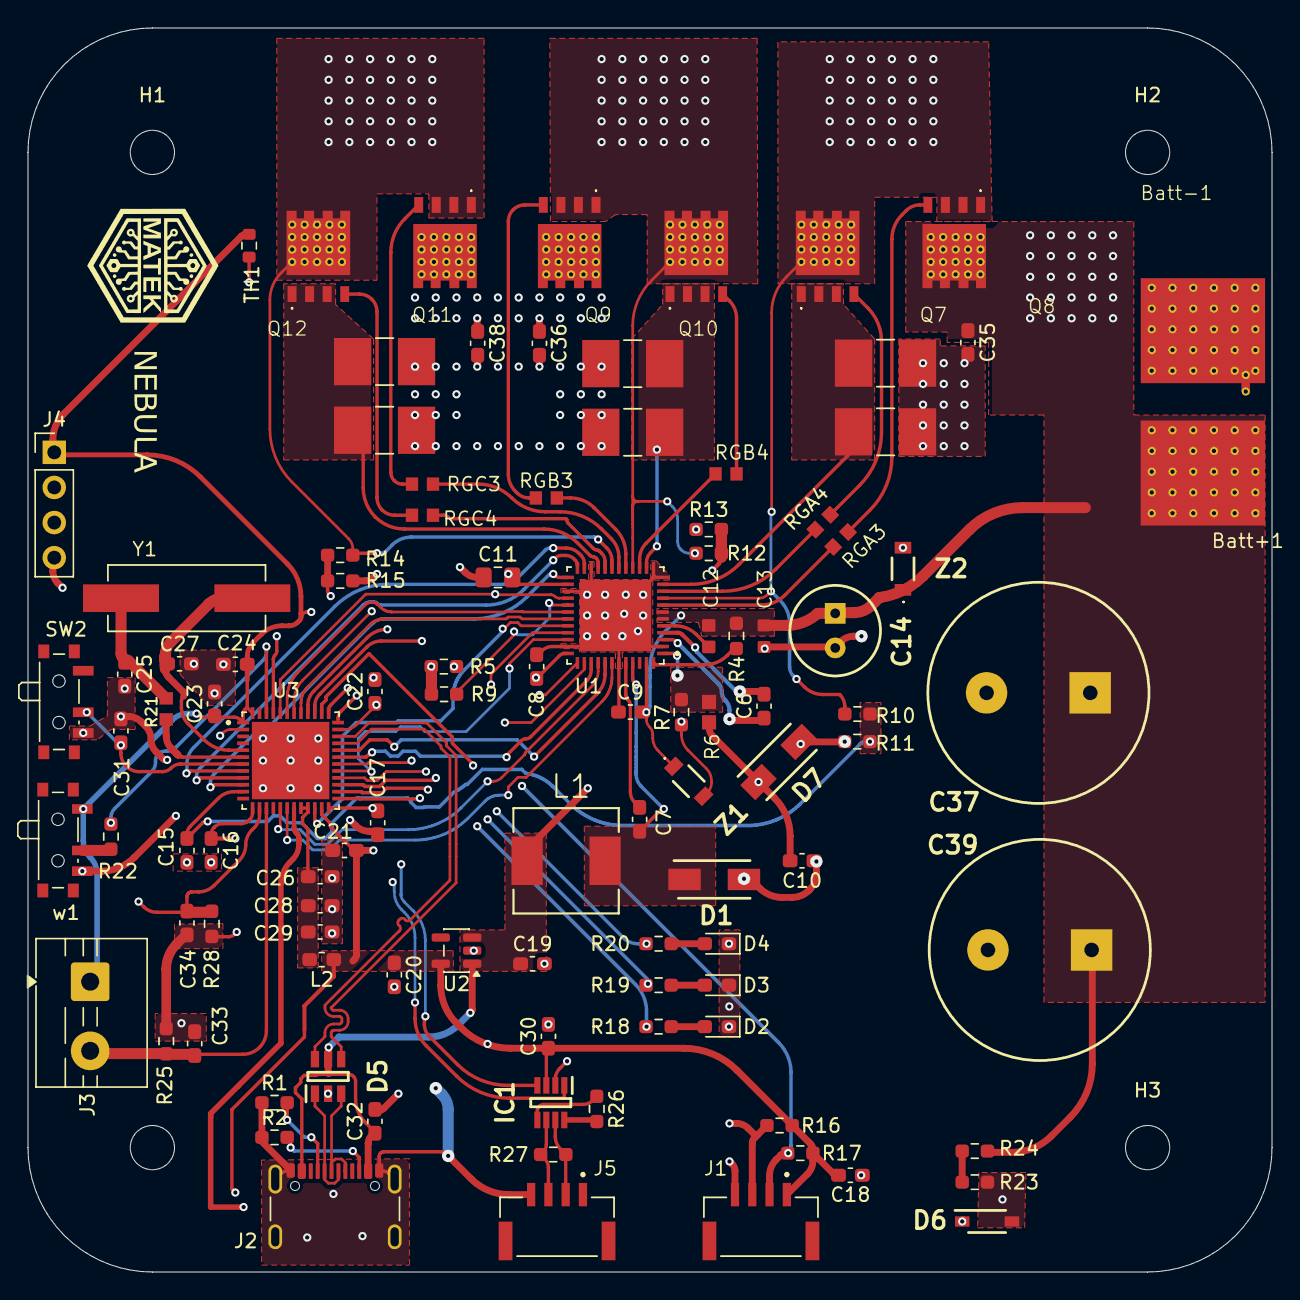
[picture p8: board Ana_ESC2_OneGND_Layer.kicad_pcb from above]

Board: 4 copper layers, 90.0 x 90.0 mm, 109 parts (0 on the bottom side), 83 nets.

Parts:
Batt+1: power_pad_smd; Power_pad_smd
Batt-1: power_pad_smd; Power_pad_smd
C6, C9: 47nF 100V; C_0603_1608Metric_Pad1.08x0.95mm_HandSolder
C7: 0.1uF 16V; C_0603_1608Metric_Pad1.08x0.95mm_HandSolder
C8: 1uF 6.3V; C_0603_1608Metric_Pad1.08x0.95mm_HandSolder
C10: 22uF 16V; C_0603_1608Metric_Pad1.08x0.95mm_HandSolder
C11: 0.1uF 6.3V; C_0805_2012Metric_Pad1.18x1.45mm_HandSolder
C12: 1uF 16V; CAPC1608X90N
C13: 0.1 uF 100V; CAPC1608X90N
C14: 22uF 100V; CAPPRD250W50D655H1250
C15, C16, C17, C29: 10nF; C_0603_1608Metric_Pad1.08x0.95mm_HandSolder
C18, C19, C20, C28, C32: 1uF; C_0603_1608Metric_Pad1.08x0.95mm_HandSolder
C21: 4u7; C_0603_1608Metric_Pad1.08x0.95mm_HandSolder
C22, C23, C24, C26, C30, C31: 100nF; C_0603_1608Metric_Pad1.08x0.95mm_HandSolder
C25, C27: 33pF; C_0603_1608Metric_Pad1.08x0.95mm_HandSolder
C33, C34, C35, C36, C38: 2.2uF; C_0603_1608Metric_Pad1.08x0.95mm_HandSolder
C37, C39: 680uF 80V; CAPPRD750W85D1600H2700
D1: SS18 80V 1A; DIOM5227X270N
D2: LEDA; LED_0603_1608Metric_Pad1.05x0.95mm_HandSolder
D3: LEDB; LED_0603_1608Metric_Pad1.05x0.95mm_HandSolder
D4: LEDC; LED_0603_1608Metric_Pad1.05x0.95mm_HandSolder
D5: USBLC6-2SC6Y; SOT95P280X145-6N
D6: D_Zener; SOD3716X135N
D7: SMAJ5.0A-E3_61; DIOM5127X229N
H1, H2, H3, H4: MountingHole; MountingHole_3.2mm_M3
IC1: TCAN330DCNT; SOT65P280X145-8N
J1, J5: BM04B-GHS-TBT_LF__SN__N_; JST_BM04B-GHS-TBT_LF__SN__N_
J2: USB_C_Receptacle_USB2.0_16P; USB_C_Receptacle_GCT_USB4105-xx-A_16P_TopMnt_Horizontal
J3: Conn_01x02_Socket; TerminalBlock_MaiXu_MX126-5.0-02P_1x02_P5.00mm
J4: Conn_01x04_Pin; PinHeader_1x04_P2.54mm_Vertical
L1: 22uH 1.6A; INDM7676X355N
L2: 100MHz / 1kR; L_0603_1608Metric_Pad1.05x0.95mm_HandSolder
NT1: NetTie_2; NetTie-2_THT_Pad0.3mm
Q7, Q8, Q9, Q10, Q11, Q12: STL90N6F7; STL90N6F7_Thermal_Vias
R1, R2: 5.1k; R_0603_1608Metric_Pad0.98x0.95mm_HandSolder
R4, R24: 100k; R_0603_1608Metric_Pad0.98x0.95mm_HandSolder
R5, R9, R16, R17, R22, R26: 10k; R_0603_1608Metric_Pad0.98x0.95mm_HandSolder
R6: 5k6; RESC1607X60N
R7, R25, R28: 1k; R_0603_1608Metric_Pad0.98x0.95mm_HandSolder
R10, R12, R14: 91k; R_0603_1608Metric_Pad0.98x0.95mm_HandSolder
R11, R13, R15: 4k7; R_0603_1608Metric_Pad0.98x0.95mm_HandSolder
R18, R19, R20: 330R; R_0603_1608Metric_Pad0.98x0.95mm_HandSolder
R21: 0ohm; RESC1508X55N
R23: 3.3k; R_0603_1608Metric_Pad0.98x0.95mm_HandSolder
R27: 120R; R_0603_1608Metric_Pad0.98x0.95mm_HandSolder
RGA3, RGA4: 0ohm; RESC1508X55N
RGB3, RGB4: 0ohm; RESC1508X55N
RGC3, RGC4: 0ohm; RESC1508X55N
Rsense_A4, Rsense_A5: 2mohm; RESC6432X80N
Rsense_B4, Rsense_B5: 2mohm; RESC6432X80N
Rsense_C4, Rsense_C5: 2mohm; RESC6432X80N
SW2: SW_SPDT; SW_SPDT_PCM12
TH1: ERT-J1VG103FA; R_0603_1608Metric
U1: DRV8323RSRGZR; QFN50P700X700X100-49N
U2: ME6211C33M5; SOT-23-5
U3: STM32G431CBU6; QFN50P700X700X60-49N
Y1: ECS-80-20-5PX-TR; XTAL_ECS-80-20-5PX-TR
Z1, Z2: KDZLVTR56
w1: SW_SPDT; SW_SPDT_PCM12

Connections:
+3.3V: C11.2, C18.1, C20.1, C21.1, C22.1, C23.1, C24.1, C30.1, IC1.3 (VCC), J1.1, J3.1, J4.1, L2.1, R16.1, R17.1, TH1.1, U1.26 (VREF), U2.5 (V_{OUT}), U3.1 (VBAT), U3.23 (VDD), U3.35 (VDD), U3.48 (VDD), w1.1 (A)
+3.3VA: C26.1, C28.1, C29.1, L2.2, U3.20 (VREF+), U3.21 (VDDA)
/Gate_Driver/CAL: U1.34 (CAL), U3.29 (PC6)
/Gate_Driver/DVDD: C8.1, R5.1, R9.1, U1.36 (DVDD)
/Gate_Driver/Enable: U1.33 (ENABLE), U3.28 (PB15)
/Gate_Driver/FAULT: R5.2, U1.28 (FAULT_N), U3.44 (PB6)
/Gate_Driver/FB: R6.1, R7.1, U1.1 (FB)
/Gate_Driver/GHA: RGA3.1, U1.8 (GHA)
/Gate_Driver/GHB: RGB3.1, U1.17 (GHB)
/Gate_Driver/GHC: RGC3.1, U1.18 (GHC)
/Gate_Driver/GLA: RGA4.1, U1.10 (GLA)
/Gate_Driver/GLB: RGB4.1, U1.15 (GLB)
/Gate_Driver/GLC: RGC4.1, U1.20 (GLC)
/Gate_Driver/INHA: U1.37 (INHA), U3.30 (PA8)
/Gate_Driver/INHB: U1.39 (INHB), U3.31 (PA9)
/Gate_Driver/INHC: U1.41 (INHC), U3.32 (PA10)
/Gate_Driver/INLA: U1.38 (INLA), U3.2 (PC13)
/Gate_Driver/INLB: U1.40 (INLB), U3.17 (PB0)
/Gate_Driver/INLC: U1.42 (INLC), U3.18 (PB1)
/Gate_Driver/SCLK: U1.31 (SCLK), U3.41 (PB3)
/Gate_Driver/SDI: U1.30 (SDI), U3.43 (PB5)
/Gate_Driver/SDO: R9.2, U1.29 (SDO), U3.42 (PB4)
/Gate_Driver/SENS1: C15.1, R10.2, R11.2, U3.11 (PA3)
/Gate_Driver/SENS2: C16.1, R12.2, R13.2, U3.13 (PA5)
/Gate_Driver/SENS3: C17.1, R14.2, R15.2, U3.24 (PB11)
/Gate_Driver/SHA: Q7.1 (S_1), Q7.2 (S_2), Q7.3 (S_3), Q8.5 (D_1), Q8.6 (D_2), Q8.7 (D_3), Q8.8 (D_4), Q8.9 (D_5), R10.1, U1.9 (SHA)
/Gate_Driver/SHB: Q9.1 (S_1), Q9.2 (S_2), Q9.3 (S_3), Q10.5 (D_1), Q10.6 (D_2), Q10.7 (D_3), Q10.8 (D_4), Q10.9 (D_5), R12.1, U1.16 (SHB)
/Gate_Driver/SHC: Q11.1 (S_1), Q11.2 (S_2), Q11.3 (S_3), Q12.5 (D_1), Q12.6 (D_2), Q12.7 (D_3), Q12.8 (D_4), Q12.9 (D_5), R14.1, U1.19 (SHC)
/Gate_Driver/SOA: U1.25 (SOA), U3.10 (PA2)
/Gate_Driver/SOB: U1.24 (SOB), U3.9 (PA1)
/Gate_Driver/SOC: U1.23 (SOC), U3.8 (PA0)
/Gate_Driver/SPA: Q8.1 (S_1), Q8.2 (S_2), Q8.3 (S_3), Rsense_A4.2, Rsense_A5.2, U1.11 (SPA)
/Gate_Driver/SPB: Q10.1 (S_1), Q10.2 (S_2), Q10.3 (S_3), Rsense_B4.2, Rsense_B5.2, U1.14 (SPB)
/Gate_Driver/SPC: Q12.1 (S_1), Q12.2 (S_2), Q12.3 (S_3), Rsense_C4.2, Rsense_C5.2, U1.21 (SPC)
/Gate_Driver/kdk: C7.1, D1.1 (K), L1.2, U1.45 (SW)
/Gate_Driver/nSCS: U1.32 (SCS_N), U3.22 (PB10)
/MCU/BOOT0: R22.2, U3.46 (PB8-BOOT0)
/MCU/CAN+: IC1.7 (CANH), J5.2, R27.2
/MCU/CAN-: IC1.6 (CANL), J5.3, R27.1
/MCU/D+: D5.3 (I/O2_1), J2.A6 (D+), J2.B6 (D+)
/MCU/D-: D5.1 (I/O1_1), J2.A7 (D-), J2.B7 (D-)
/MCU/I2C1_SCL: J1.2, R17.2, U3.38 (PA15)
/MCU/I2C1_SDA: J1.3, R16.2, U3.45 (PB7)
/MCU/NTC_FET: C34.1, R28.2, TH1.2, U3.14 (PA6)
/MCU/NTC_MTR: C33.1, J3.2, R25.2, U3.15 (PA7)
/MCU/PD2: IC1.8 (S), R26.2
/MCU/RST: C31.1, SW2.2 (B), U3.7 (PG10-~RST)
/MCU/SWCLK: J4.3, U3.37 (PA14)
/MCU/SWDIO: J4.2, U3.36 (PA13)
/MCU/UART_N: IC1.4 (RXD), U3.39 (PC10)
/MCU/UART_P: IC1.1 (TXD), U3.40 (PC11)
/MCU/USB_DN: D5.6 (I/O1_2), U3.33 (PA11)
/MCU/USB_DP: D5.4 (I/O2_2), U3.34 (PA12)
/MCU/VBus: D6.1 (K), U3.19 (PB2)
GND: Batt-1.1, C8.2, C9.1, C10.1, C11.1, C13.2, C14.2 (-), C35.2, C36.2, C37.2 (-), C38.2, C39.2 (-), D1.2 (A), D7.2 (A), NT1.1, R7.2, R11.1, R13.1, R15.1, Rsense_A4.1, Rsense_A5.1, Rsense_B4.1, Rsense_B5.1, Rsense_C4.1, Rsense_C5.1, U1.2 (PGND), U1.12 (SNA), U1.13 (SNB), U1.22 (SNC), U1.27 (DGND), U1.35 (AGND), U1.43 (BGND), U1.49 (EP), Z1.2 (A), Z2.2 (A)
GND2: C15.2, C16.2, C17.2, C18.2, C19.2, C20.2, C21.2, C22.2, C23.2, C24.2, C25.2, C26.2, C27.2, C28.2, C29.2, C30.2, C31.2, C32.2, C33.2, C34.2, D2.1 (K), D3.1 (K), D4.1 (K), D5.2 (GND), D6.2 (A), IC1.2 (GND), J1.4, J2.A1 (GND), J2.A12 (GND), J2.B1 (GND), J2.B12 (GND), J2.S1 (SHIELD), J4.4, J5.4, NT1.2, R1.1, R2.1, R23.2, R25.1, R28.1, SW2.3 (C), U2.2 (V_{SS}), U3.49 (VSS), w1.3 (C)
MCU_PWR: C10.2, C19.1, C32.1, D5.5 (VBUS), D7.1 (K), J2.A4 (VBUS), J2.A9 (VBUS), J2.B4 (VBUS), J2.B9 (VBUS), L1.1, R6.2, U2.1 (V_{IN}), U2.3 (CE)
unnamed: C25.1, R21.2, Y1.1
unnamed: D2.2 (A), R18.1
unnamed: D3.2 (A), R19.1
unnamed: D4.2 (A), R20.1
unnamed: IC1.5 (SHDN), R26.1
unnamed: J2.A5 (CC1), R1.2
unnamed: J2.B5 (CC2), R2.2
unnamed: Q7.4 (G), RGA3.2
unnamed: Q8.4 (G), RGA4.2
unnamed: Q9.4 (G), RGB3.2
unnamed: Q10.4 (G), RGB4.2
unnamed: Q11.4 (G), RGC3.2
unnamed: Q12.4 (G), RGC4.2
unnamed: R23.1, R24.2
unnamed: C7.2, U1.44 (CB)
unnamed: C6.2, U1.4 (CPH)
unnamed: C6.1, U1.3 (CPL)
unnamed: R4.2, U1.48 (SHDN_N)
unnamed: C12.1, U1.5 (VCP)
unnamed: R18.2, U3.25 (PB12)
unnamed: R19.2, U3.26 (PB13)
unnamed: R20.2, U3.27 (PB14)
unnamed: C27.1, U3.5 (PF0-OSC_IN), Y1.2
unnamed: R21.1, U3.6 (PF1-OSC_OUT)
unnamed: R22.1, w1.2 (B)
VM: Batt+1.1, C9.2, C12.2, C13.1, C14.1 (+), C35.1, C36.1, C37.1 (+), C38.1, C39.1 (+), Q7.5 (D_1), Q7.6 (D_2), Q7.7 (D_3), Q7.8 (D_4), Q7.9 (D_5), Q9.5 (D_1), Q9.6 (D_2), Q9.7 (D_3), Q9.8 (D_4), Q9.9 (D_5), Q11.5 (D_1), Q11.6 (D_2), Q11.7 (D_3), Q11.8 (D_4), Q11.9 (D_5), R4.1, R24.1, U1.6 (VM), U1.7 (VDRAIN), U1.47 (VIN), Z1.1 (K), Z2.1 (K)

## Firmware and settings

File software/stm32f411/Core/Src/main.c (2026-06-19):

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
/* Includes ------------------------------------------------------------------*/
#include "main.h"
#include "cmsis_os.h"
#include "usb_device.h"

/* USER CODE BEGIN Includes */
#include "bsp.h"
/* USER CODE END Includes */

ADC_HandleTypeDef hadc1;
DMA_HandleTypeDef hdma_adc1;

CRC_HandleTypeDef hcrc;

SPI_HandleTypeDef hspi1;

TIM_HandleTypeDef htim1;

/* Definitions for defaultTask */
osThreadId_t defaultTaskHandle;
const osThreadAttr_t defaultTask_attributes = {
  .name = "defaultTask",
  .stack_size = 512 * 4,
  .priority = (osPriority_t) osPriorityNormal,
};
/* Definitions for telemTask */
osThreadId_t telemTaskHandle;
const osThreadAttr_t telemTask_attributes = {
  .name = "telemTask",
  .stack_size = 512 * 4,
  .priority = (osPriority_t) osPriorityLow,
};
/* Definitions for commTask */
osThreadId_t commTaskHandle;
const osThreadAttr_t commTask_attributes = {
  .name = "commTask",
  .stack_size = 1024 * 4,
  .priority = (osPriority_t) osPriorityAboveNormal,
};
void SystemClock_Config(void);
static void MX_GPIO_Init(void);
static void MX_DMA_Init(void);
static void MX_TIM1_Init(void);
static void MX_ADC1_Init(void);
static void MX_SPI1_Init(void);
static void MX_CRC_Init(void);
void StartDefaultTask(void *argument);
extern void TelemThread(void *argument);
extern void CommThread(void *argument);

/**
  * @brief  The application entry point.
  * @retval int
  */
int main(void)
{

  /* MCU Configuration--------------------------------------------------------*/

  /* Reset of all peripherals, Initializes the Flash interface and the Systick. */
  HAL_Init();

  /* Configure the system clock */
  SystemClock_Config();

  /* Initialize all configured peripherals */
  MX_GPIO_Init();
  MX_DMA_Init();
  MX_TIM1_Init();
  MX_ADC1_Init();
  MX_SPI1_Init();
  MX_CRC_Init();
  /* USER CODE BEGIN 2 */
	bsp_init();
	bldc_comm_init(bsp_get_motor_handle());
  bldc_telem_init();
  // bldc_dronecan_init();
  // bldc_drv8323r_init();
  /* USER CODE END 2 */

  /* Init scheduler */
  osKernelInitialize();

  /* USER CODE BEGIN RTOS_MUTEX */
  /* add mutexes, ... */
  /* USER CODE END RTOS_MUTEX */

  /* USER CODE BEGIN RTOS_SEMAPHORES */
  /* add semaphores, ... */
  /* USER CODE END RTOS_SEMAPHORES */

  /* USER CODE BEGIN RTOS_TIMERS */
  /* start timers, add new ones, ... */
  /* USER CODE END RTOS_TIMERS */

  /* USER CODE BEGIN RTOS_QUEUES */
  /* add queues, ... */
  /* USER CODE END RTOS_QUEUES */

  /* Create the thread(s) */
  /* creation of defaultTask */
  defaultTaskHandle = osThreadNew(StartDefaultTask, NULL, &defaultTask_attributes);

  /* creation of telemTask */
  telemTaskHandle = osThreadNew(TelemThread, NULL, &telemTask_attributes);

  /* creation of commTask */
  commTaskHandle = osThreadNew(CommThread, NULL, &commTask_attributes);

  /* USER CODE BEGIN RTOS_THREADS */
  /* add threads, ... */
  /* USER CODE END RTOS_THREADS */

  /* USER CODE BEGIN RTOS_EVENTS */
  /* add events, ... */
  /* USER CODE END RTOS_EVENTS */

  /* Start scheduler */
  osKernelStart();

  /* We should never get here as control is now taken by the scheduler */

  /* Infinite loop */
  /* USER CODE BEGIN WHILE */
  while (1)
  {
    /* USER CODE END WHILE */

    /* USER CODE BEGIN 3 */
  }
  /* USER CODE END 3 */
}

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
/* USER CODE BEGIN Header_StartDefaultTask */
/**
  * @brief  Function implementing the defaultTask thread.
  * @param  argument: Not used
  * @retval None
  */
/* USER CODE END Header_StartDefaultTask */
void StartDefaultTask(void *argument)
{
  /* init code for USB_DEVICE */
  MX_USB_DEVICE_Init();
  /* USER CODE BEGIN 5 */
  /* Infinite loop */
  for(;;)
  {
		osDelay(10);
	}
  /* USER CODE END 5 */
}

/**
  * @brief  Period elapsed callback in non blocking mode
  * @note   This function is called  when TIM5 interrupt took place, inside
  * HAL_TIM_IRQHandler(). It makes a direct call to HAL_IncTick() to increment
  * a global variable "uwTick" used as application time base.
  * @param  htim : TIM handle
  * @retval None
  */
void HAL_TIM_PeriodElapsedCallback(TIM_HandleTypeDef *htim)
{
  if (htim->Instance == TIM5)
  {
    HAL_IncTick();
  }
  /* USER CODE BEGIN Callback 1 */
#if CONFIG_FOC_ENABLE
  extern void bldc_foc_hal_period_callback(TIM_HandleTypeDef *htim);
  bldc_foc_hal_period_callback(htim);
#endif
  /* USER CODE END Callback 1 */
}

/**
  * @brief  This function is executed in case of error occurrence.
  * @retval None
  */
void Error_Handler(void)
{
  /* USER CODE BEGIN Error_Handler_Debug */
  /* User can add his own implementation to report the HAL error return state */
  __disable_irq();
  while (1)
  {
  }
  /* USER CODE END Error_Handler_Debug */
}
#ifdef USE_FULL_ASSERT
/**
  * @brief  Reports the name of the source file and the source line number
  *         where the assert_param error has occurred.
  * @param  file: pointer to the source file name
  * @param  line: assert_param error line source number
  * @retval None
  */
void assert_failed(uint8_t *file, uint32_t line)
{
  /* USER CODE BEGIN 6 */
  /* User can add his own implementation to report the file name and line number,
     ex: printf("Wrong parameters value: file %s on line %d\r\n", file, line) */
  /* USER CODE END 6 */
}
#endif /* USE_FULL_ASSERT */

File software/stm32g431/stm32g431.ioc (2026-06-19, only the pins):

Mcu.UserName=STM32G431CBUx
PA0.GPIO_Label=Curr_Sense_A
PA0.Signal=ADC1_IN1
PA1.GPIO_Label=Curr_Sense_B
PA1.Signal=ADC1_IN2
PA10.GPIO_Label=INH3
PA10.Signal=S_TIM1_CH3
PA11.Signal=USB_DM
PA12.Signal=USB_DP
PA13.Signal=SYS_JTMS-SWDIO
PA14.Signal=SYS_JTCK-SWCLK
PA15.Signal=I2C1_SCL
PA2.GPIO_Label=Curr_Sense_C
PA2.Signal=ADC1_IN3
PA6.GPIO_Label=NTC_Mosfet
PA6.Signal=ADC2_IN3
PA7.GPIO_Label=NTC_Motor
PA7.Signal=ADC2_IN4
PA8.GPIO_Label=INH1
PA8.Signal=S_TIM1_CH1
PA9.GPIO_Label=INH2
PA9.Signal=S_TIM1_CH2
PB0.GPIO_Label=INL2
PB0.Signal=TIM1_CH2N
PB1.GPIO_Label=INL3
PB1.Signal=TIM1_CH3N
PB13.GPIO_Label=SPI1_EN
PB13.Signal=GPIO_Output
PB14.GPIO_Label=SPI1_CS
PB14.Signal=GPIO_Output
PB2.GPIO_Label=V_Bus_Sense
PB2.Signal=ADC2_IN12
PB3.Signal=SPI1_SCK
PB4.Signal=SPI1_MISO
PB5.Signal=SPI1_MOSI
PB7.Signal=I2C1_SDA
PB8-BOOT0.Signal=FDCAN1_RX
PB9.Signal=FDCAN1_TX
PC10.Signal=UART4_TX
PC11.Signal=UART4_RX
PC13.GPIO_Label=INL1
PC13.Signal=TIM1_CH1N
PC15-OSC32_OUT.Signal=RCC_OSC32_OUT
PF0-OSC_IN.Signal=RCC_OSC_IN
PF1-OSC_OUT.Signal=RCC_OSC_OUT

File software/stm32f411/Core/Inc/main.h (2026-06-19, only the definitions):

#define INLA_Pin GPIO_PIN_13
#define INLA_GPIO_Port GPIOC
#define ADC_Ph0_Curr_Pin GPIO_PIN_0
#define ADC_Ph0_Curr_GPIO_Port GPIOA
#define ADC_Ph1_Curr_Pin GPIO_PIN_1
#define ADC_Ph1_Curr_GPIO_Port GPIOA
#define ADC_Ph2_Curr_Pin GPIO_PIN_2
#define ADC_Ph2_Curr_GPIO_Port GPIOA
#define SENS1_Pin GPIO_PIN_3
#define SENS1_GPIO_Port GPIOA
#define V_Bus_Sense_Pin GPIO_PIN_5
#define V_Bus_Sense_GPIO_Port GPIOA
#define NTC_FET_Pin GPIO_PIN_6
#define NTC_FET_GPIO_Port GPIOA
#define NTC_MTR_Pin GPIO_PIN_7
#define NTC_MTR_GPIO_Port GPIOA
#define INLB_Pin GPIO_PIN_0
#define INLB_GPIO_Port GPIOB
#define INLC_Pin GPIO_PIN_1
#define INLC_GPIO_Port GPIOB
#define SPI1_CS_Pin GPIO_PIN_2
#define SPI1_CS_GPIO_Port GPIOB
#define PROT_D4_Pin GPIO_PIN_13
#define PROT_D4_GPIO_Port GPIOB
#define PROT_D5_Pin GPIO_PIN_14
#define PROT_D5_GPIO_Port GPIOB
#define INHA_Pin GPIO_PIN_8
#define INHA_GPIO_Port GPIOA
#define INHB_Pin GPIO_PIN_9
#define INHB_GPIO_Port GPIOA
#define INHC_Pin GPIO_PIN_10
#define INHC_GPIO_Port GPIOA
#define SPI1_EN_Pin GPIO_PIN_6
#define SPI1_EN_GPIO_Port GPIOB
#define SPI1_FAULT_Pin GPIO_PIN_7
#define SPI1_FAULT_GPIO_Port GPIOB
#define MAJOR_SW 1
#define MINOR_SW 0
#define MAJOR_HW 1
#define MINOR_HW 0
#define HAS_HW_RNG 1
#define HAS_HW_RNG 0

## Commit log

2026-02-20 Added existing files
    We need to think about:
    Sensorless FOC driving technique sensing method for knowing the position of rotor, and so we can activate related phases.
    [Ana_ESC.kicad_pcb, Ana_ESC.kicad_sch, Gate_Driver.kicad_sch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]
2026-03-10 lib file added -step file, symbol file and footprints-
2026-03-10 Update notes on motor driver circuit and Mosfet analysis
    Added general notes about the motor driver circuit and updated the analysis of the Mosfet driver IC's current limit.
2026-03-10 mosfet v2
    [Ana_ESC.kicad_sch, mosfet_v2.kicad_sch, mosfetv2.kicad_sch]
2026-03-10 reference files added
    [mosfet_v2.kicad_sch]
2026-03-12 Component List added from Digikey
    [ESC_Component_List.xlsx]
2026-03-12 MCU schematics update
    [Ana_ESC.kicad_sch, MCU.kicad_sch]
2026-03-12 cube ide file added for stm32g431
2026-03-12 some pins changes"
    [Ana_ESC.kicad_sch, MCU.kicad_sch]
2026-03-21 Revert "nothing"
    This reverts commit c8bc8ca9c45f61fe26da700702173eff74c7b1f5.
    [Gate_Driver.kicad_sch, MCU.kicad_sch]
2026-03-21 current sense -> bemf switch
    [MCU.kicad_sch]
2026-03-21 added ntc sensor
    [MCU.kicad_sch]
2026-03-21 vbus / current sense pins on MCU
    [MCU.kicad_sch]
2026-03-21 RST pin
    [Gate_Driver.kicad_sch, MCU.kicad_sch]
2026-03-22 thermal calculations done and Shunt Resistors changed. Not 3, just 2 resistors can dissipate the power.
    [Ana_ESC.kicad_pcb, Ana_ESC.kicad_sch, mosfetv2.kicad_sch]
2026-03-24 Footprints prepared, first pcb project created.
    [Ana_ESC.kicad_pcb, Ana_ESC.kicad_sch, Ana_ESC_yedek_sali_24_03_2026.kicad_sch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]
2026-03-30 component list updated, all footprints updated and now they are compatible to produce with hand (no 0402 size)
    [Ana_ESC.kicad_pcb, ESC_Component_List.xlsx, Gate_Driver.kicad_sch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]
2026-03-31 some tags chaneged, pcb thinked about pcb component placement, aluminum mosfet carrier pcb and paralelling mosfets
    [Gate_Driver.kicad_sch, MCU.kicad_sch, Mosfets.kicad_sch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]
2026-04-10 starting with pcb (kicad_pcb (version 20241229) (generator "pcbnew") (generator_version "9.0") (layers (0 "F.Cu" signal) (2 "B.Cu" signal) (9 "F.Adhes" user "F.Adhesive") (11 "B.Adhes" user "B.Adhesi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
    [Ana_ESC.kicad_pcb, MCU.kicad_sch]
2026-04-10 started to pcb design, mosfets,shunts drv8323 placement.
    [Ana_ESC.kicad_pcb, Gate_Driver.kicad_sch, mosfetv2.kicad_sch]
2026-04-13 new pcb
    [Ana_ESC.kicad_pcb, MCU.kicad_sch, freerouting.dsn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]
2026-04-13 pcb - mcu part +
    [Ana_ESC.kicad_pcb, MCU.kicad_sch]
2026-04-15 all nıght 4/12
    [Ana_ESC.kicad_pcb, Gate_Driver.kicad_sch, MCU.kicad_sch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]
2026-04-22 Some pcb design and schematics editings about PGND_DRV
    [Ana_ESC.kicad_pcb, Gate_Driver.kicad_sch, mosfetv2.kicad_sch]
2026-04-22 all routed pcb
    [Ana_ESC.kicad_pcb, Gate_Driver.kicad_sch, MCU.kicad_sch]
2026-04-25 fixing design errors
    [Ana_ESC.kicad_pcb]
2026-05-11 New one_GND_Layer pcb desgin has finished yet. DRC Rule checks needs to be controlling and correcting still.
    [Ana_ESC.kicad_pcb, Ana_ESC2_OneGND_Layer.kicad_pcb, Gate_Driver.kicad_sch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]
2026-05-11 some drc rule checks and correcting
    [Ana_ESC2_OneGND_Layer.kicad_pcb, MCU.kicad_sch]
2026-05-12 minor rule checking warning
    [Ana_ESC2_OneGND_Layer.kicad_pcb]
2026-05-12 3d objects and pdf
    [Ana_ESC2_OneGND_Layer.kicad_pcb]
2026-05-14 BOM list prepared for ekom and direnc.net
    [Ana_ESC2_OneGND_Layer.csv, Ana_ESC2_OneGND_Layer.kicad_pcb, Ana_ESC2_OneGND_Layer_v2.csv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]
2026-05-14 for LCSC components the layout/footprints changed. Previous commit for ekom/direncnet components.
    [Ana_ESC2_OneGND_Layer.kicad_pcb, Ana_ESC2_OneGND_Layer_v6.csv, Gate_Driver.kicad_sch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]
2026-06-17 arranged into hardware and software
    [Ana_ESC.kicad_pcb, Ana_ESC.kicad_sch, Ana_ESC2_OneGND_Layer.csv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]
2026-06-18 proper random data for stm32f411
2026-06-18 python script to monitor prints
2026-06-18 commutaition implementation perhaps not working
    [board.c, bsp.h, commutation.c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]
2026-06-19 ADC DMA on stm32f411
2026-06-19 V bus sensing, power usage and
2026-06-19 dynamic loop speed for reading and transmittting, device id added to telem data
2026-06-19 Fixing "G431 uses polled ADC in the FOC loop — same path as telemetry snapshot."
    [board.c, bsp.h, main.c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]
2026-06-19 OC4Ref ADC1 PWM tripger to prevent interruption from codegen
    [board.c, main.c]
2026-06-19 fixing some startups strategyies
    [bsp.h, observer.c, telem.c]
2026-06-30 final project board layout is in this commit
    [Ana_ESC.kicad_pcb, Ana_ESC.kicad_sch, Ana_ESC2_OneGND_Layer-Edge_Cuts.dxf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]
2026-07-17 After graduation presantition. USB differantial ways improved for usb connection issue. DRV83233 Enable and nSCS pins changed to be in true connection with STM32G431. ETC
    [Ana_ESC2_OneGND_Layer-B_Cu.gbr, Ana_ESC2_OneGND_Layer-B_Mask.gbr, Ana_ESC2_OneGND_Layer-B_Silkscreen.gbr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]

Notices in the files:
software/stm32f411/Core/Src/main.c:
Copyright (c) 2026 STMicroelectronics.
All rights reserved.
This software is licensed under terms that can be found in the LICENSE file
